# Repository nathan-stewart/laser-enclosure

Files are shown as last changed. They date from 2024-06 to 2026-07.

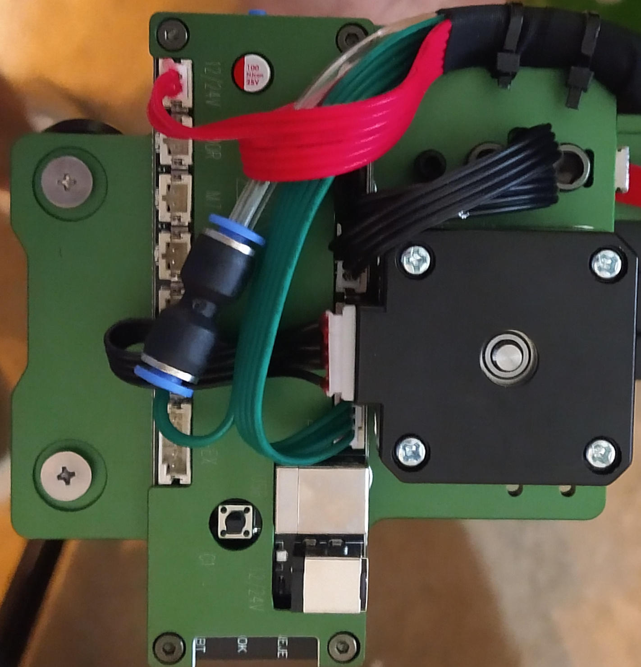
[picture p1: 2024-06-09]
neje-max-4/IMG_20240601_095933033.jpg

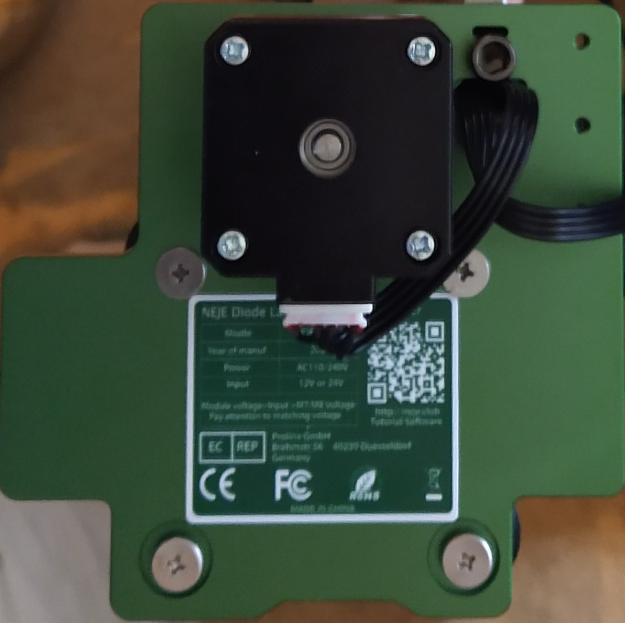
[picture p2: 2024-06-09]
neje-max-4/IMG_20240601_095917464.jpg

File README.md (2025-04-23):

# Laser Enclosure Fire Control Diagrams

This repository contains Graphviz DOT diagrams for documenting the fire suppression logic and relay control layout in a Raspberry Pi-controlled laser enclosure project.

## Included Files

### `fire_state_machine.dot`
- Describes the FIRE state logic.
- **ARMED**: Tank is pressurized (system ready).
- **FIRE**: Triggered by pressure drop, CO₂ valve opens, gates close.
- **RESET**: Performed via E-stop twist.
- Use `dot -Tpng fire_state_machine.dot -o fire_state_machine.png` to render.

### `power_distribution.dot`
- Updated relay layout with sequential relay numbering:
  - `K1`: Laser
  - `K2`: High Pressure Air (HPA)
  - `K3`: CO₂ Valve
  - `K4`: Blast Gates (intake/exhaust)
  - `K5`: Low Pressure Air (LPA)
  - `K6`: Heater Fan
  - `K7`: Exhaust Fan
  - `K8`: PTC Heater (AC)
- Use `dot -Tpng relay_layout_k3_k4_separated.dot -o relay_layout_k3_k4_separated.png` to render.

## Notes

- Gates are gravity-closing and do not remain activated after a FIRE event.
- CO₂ valve remains open until a manual reset is performed.
- The system arms based on tank pressure and triggers on pressure drop.
- Relays are powered from 24V, 12V, and AC lines as appropriate.

## Rendering

Install [Graphviz](https://graphviz.org/download/) and run:

```bash
dot -Tpng fire_state_machine.dot -o fire_state_machine.png
dot -Tpng power_distribution.dot -o power_distribution.png
```

Or use online editors like [edotor.net](https://edotor.net/) or [dreampuf.github.io](https://dreampuf.github.io/GraphvizOnline/).

---

**Enginerd-built. Fire-tested.** 🔥🛠️

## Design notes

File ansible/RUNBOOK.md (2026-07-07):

# Laser Enclosure Ansible Runbook

This folder intentionally has only three normal commands.

```bash
cd ansible
make ping
make app
make site
```

## Normal app/code update

Use this after changing HAL/control code, systemd unit files, GPIO boot block, or the halctl plugin source copied with the app.

```bash
make app DRY=1
make app
```

## Full box update

Use this for a rebuild or when base OS/kiosk/MeerK40t setup may need to be reapplied.

```bash
make site DRY=1
make site
```

## One-off narrower runs

Do not add a Makefile target for every Ansible feature. Use `EXTRA` when needed:

```bash
make site EXTRA='--tags meerk40t'
make site EXTRA='--tags base'
make app EXTRA='--tags gpio-config'
make app EXTRA='-vv'
```

## Live HAL commands

```bash
halctl get
halctl exhaust on
halctl exhaust off
halctl exhaust 600
```

## Current hardware notes

- Laser has its own fused 24 V feed.
- 12 V rail is fused and currently parked/reserved for future front panel.
- Spare moved from K4 to K2; verify code and GPIO comments match actual wiring.
- RJ45 fanout removed.
- PSU moved underneath board for space and airflow.
- White PowerCONs are switched 120 VAC outputs for DRY and FAN.

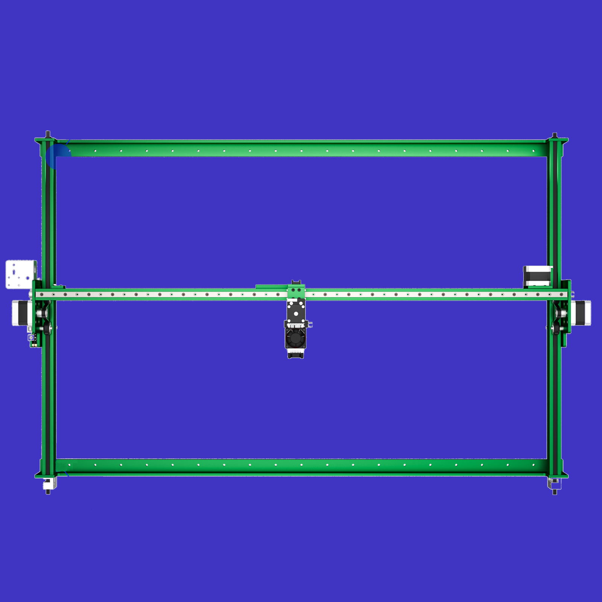
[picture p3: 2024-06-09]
neje-max-4/drawing-xy.jpg

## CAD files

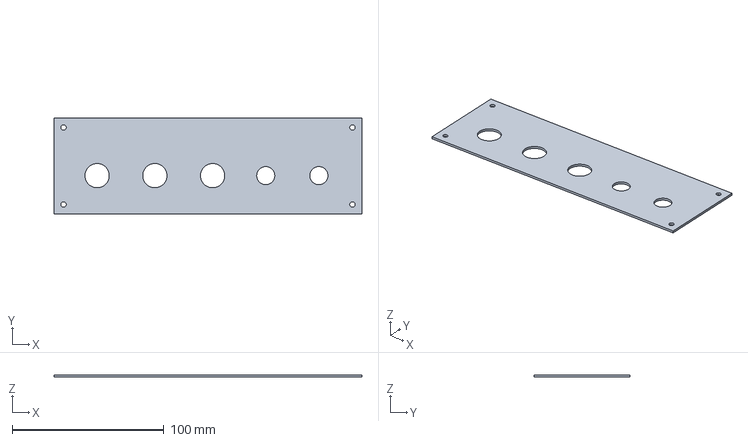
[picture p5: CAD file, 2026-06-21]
aluminum-bottom-panel.FCStd
203.2 x 63.5 x 1.52 mm

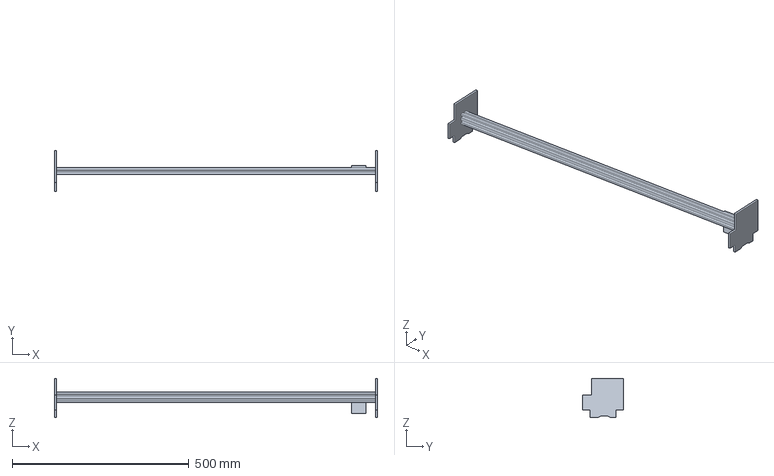
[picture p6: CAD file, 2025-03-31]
neje-max-4/x-rail.FCStd
914.2 x 116.0 x 111.0 mm

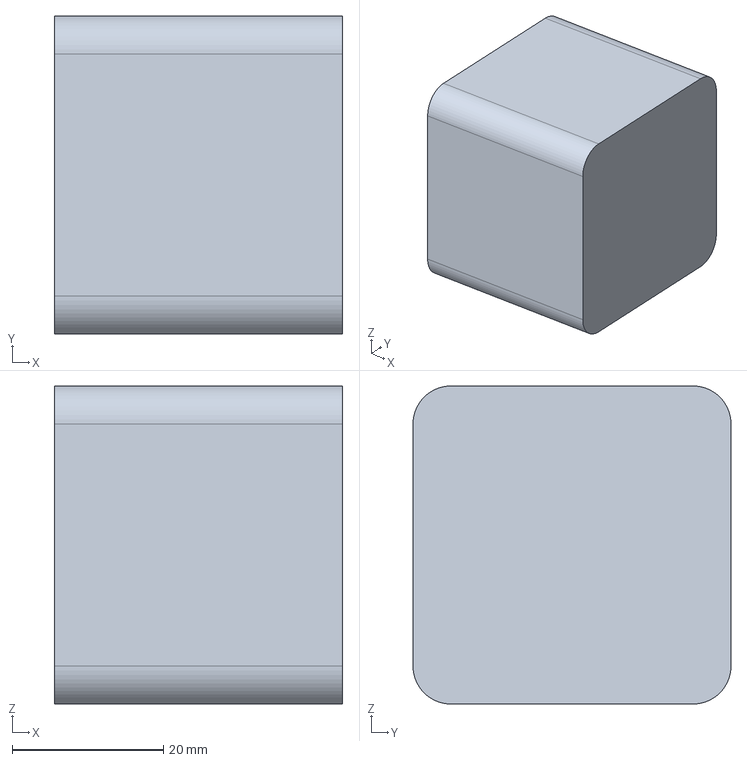
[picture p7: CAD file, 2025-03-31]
neje-max-4/nema-17.FCStd
38.1 x 42.0 x 42.0 mm

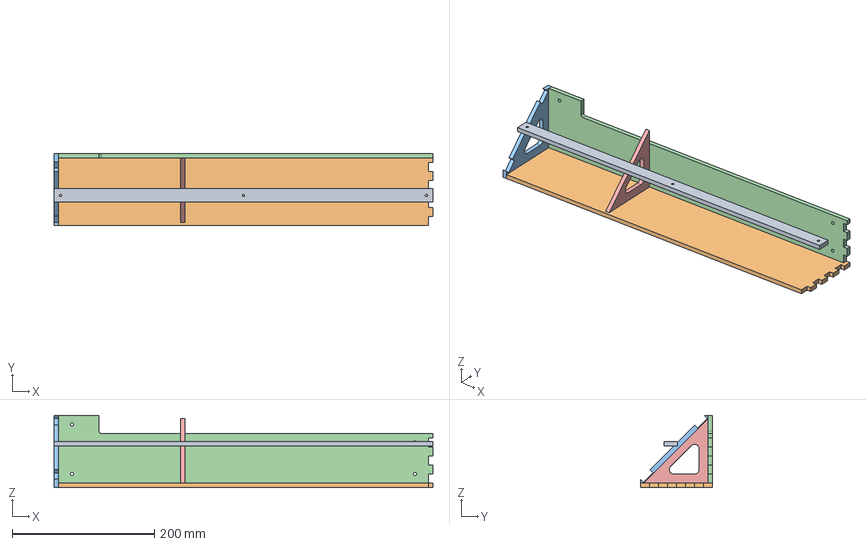
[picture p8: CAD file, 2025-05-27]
panel-support.FCStd
533.4 x 101.6 x 101.6 mm
floor
endcap
back
rib

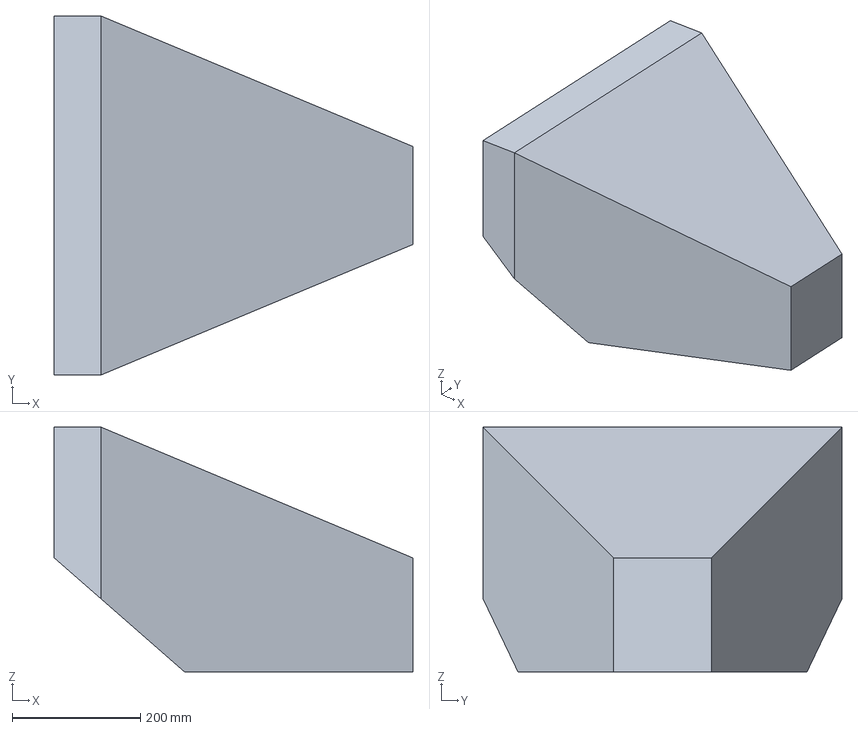
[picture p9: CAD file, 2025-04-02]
foamcore-duct.FCStd
558.8 x 558.8 x 381.0 mm

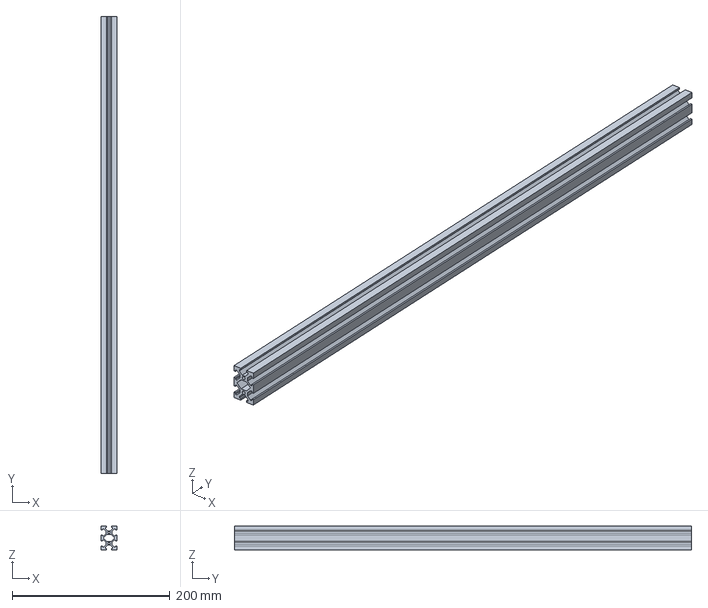
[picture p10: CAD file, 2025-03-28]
neje-max-4/y-extrusion.FCStd
20.0 x 580.0 x 30.0 mm

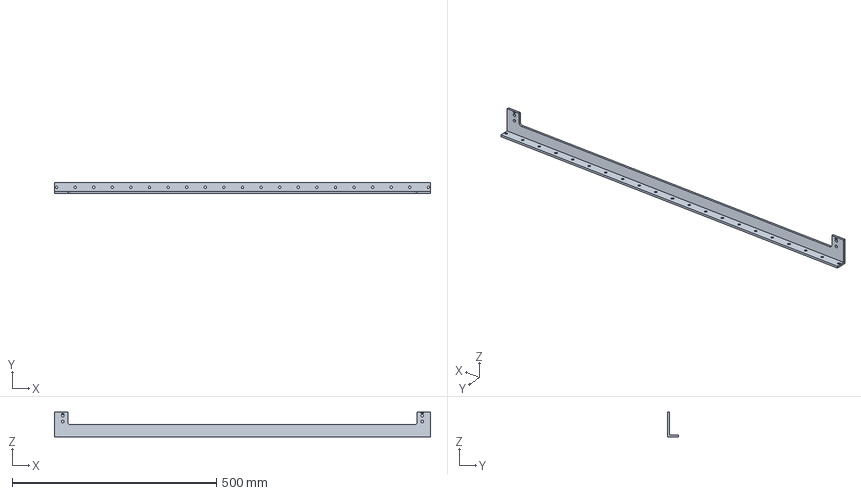
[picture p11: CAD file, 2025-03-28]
neje-max-4/x-frame.FCStd
920.0 x 26.0 x 60.0 mm

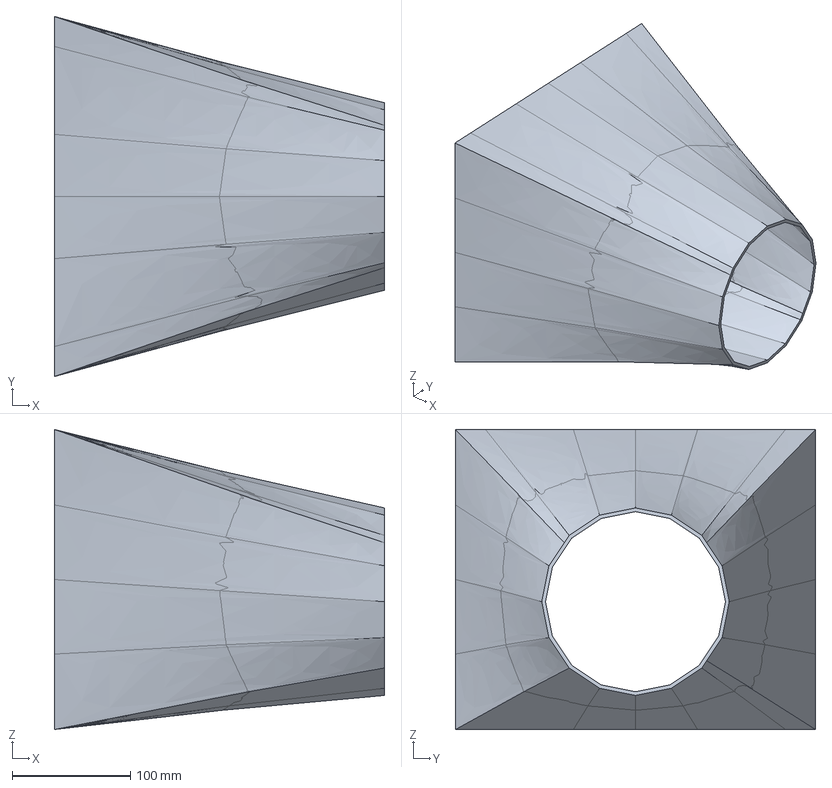
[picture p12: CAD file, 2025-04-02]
square-to-round.FCStd
279.4 x 304.8 x 254.0 mm

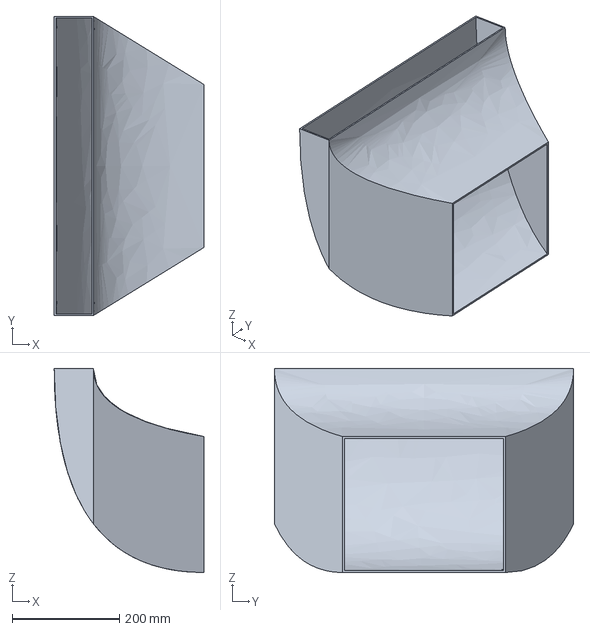
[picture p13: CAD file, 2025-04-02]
elbow.FCStd
279.4 x 558.8 x 381.0 mm

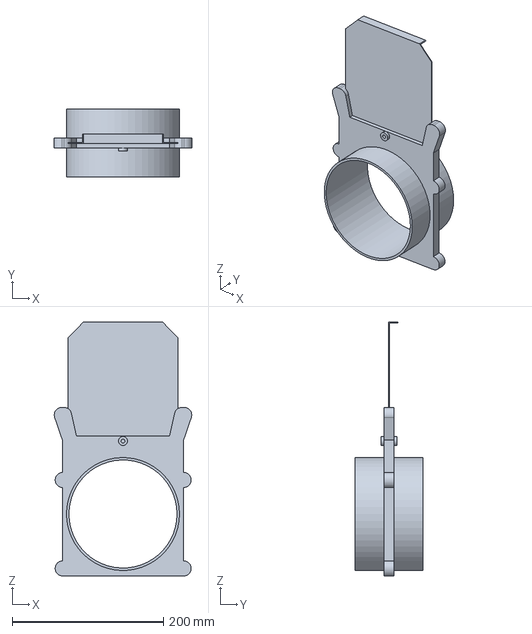
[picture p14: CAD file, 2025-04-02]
blastgate.FCStd
182.0 x 89.9 x 336.0 mm

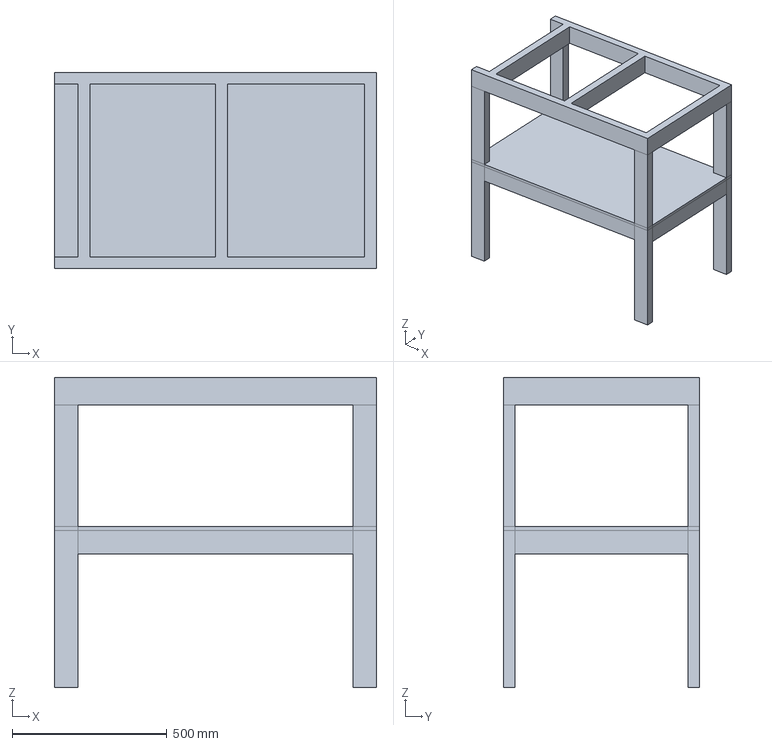
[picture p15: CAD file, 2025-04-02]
base.FCStd
1041.4 x 635.0 x 1003.3 mm

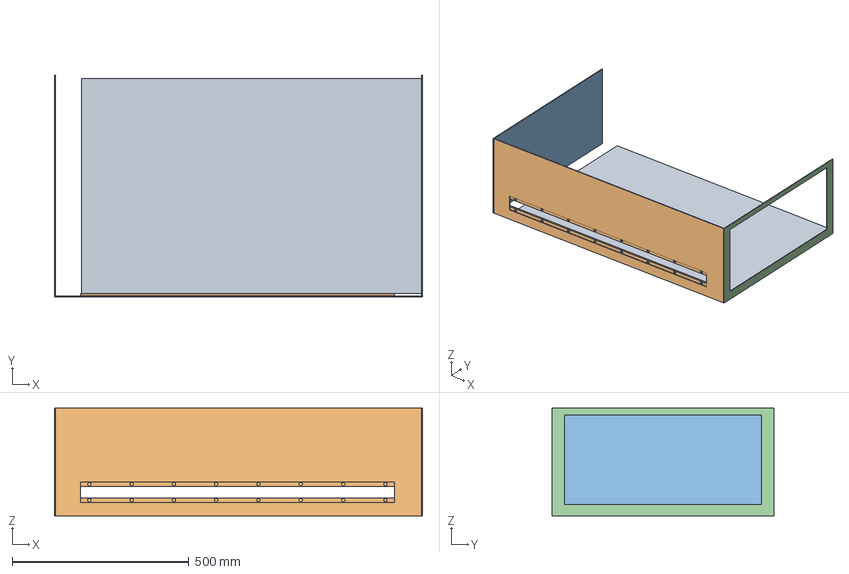
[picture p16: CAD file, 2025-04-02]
enclosure.FCStd
1041.4 x 628.6 x 304.8 mm
front
left
right

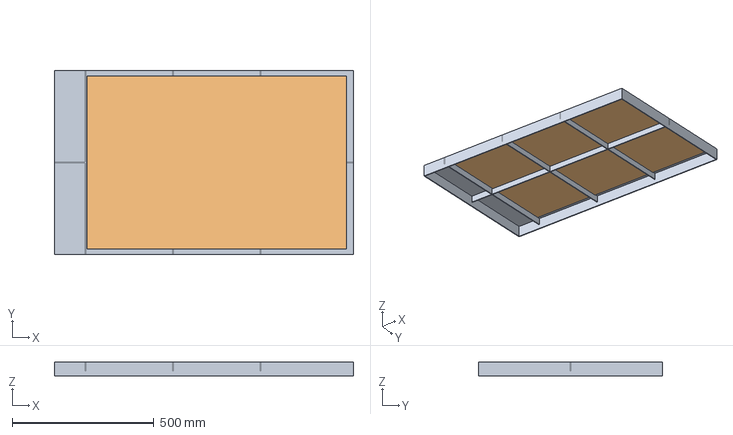
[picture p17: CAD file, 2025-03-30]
lid.FCStd
1054.1 x 647.7 x 50.8 mm
top
window

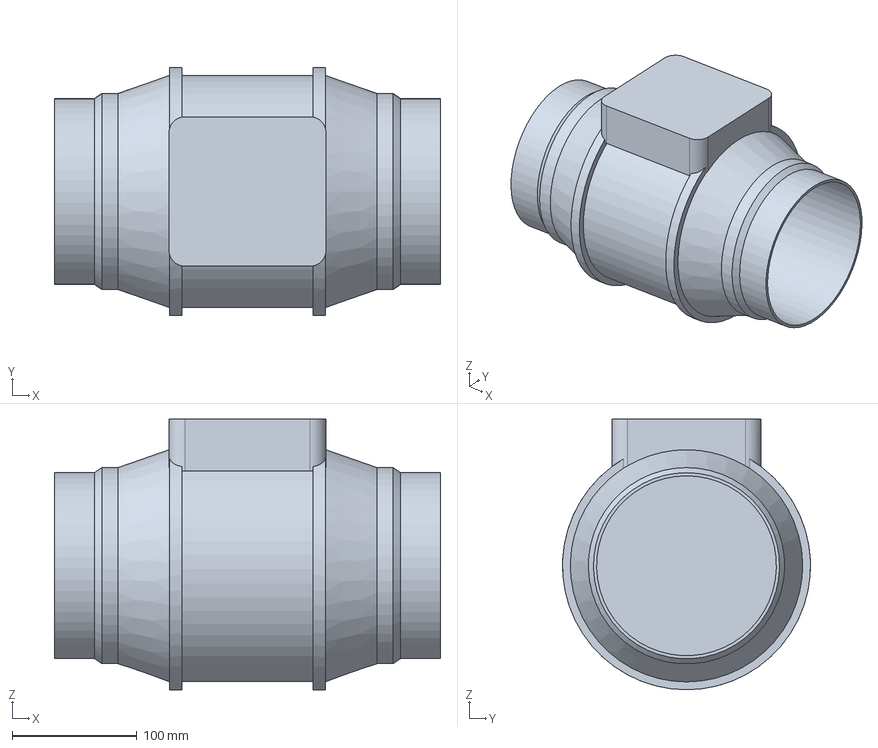
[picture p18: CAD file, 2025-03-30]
exhaust-fan.FCStd
309.9 x 199.0 x 217.2 mm

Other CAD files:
enclosure-assy.FCStd
neje-max-4/x-rail-assy.FCStd
neje-max-4/neje-max-4.FCStd
plug-mount.FCStd
90deg-register-box.FCStd
air-assist.FCStd
door.FCStd
dragchain-link.FCStd
dragchain-start.FCStd
duct-transition.FCStd
enclosure-dims.FCStd
enclosure-exploded.FCStd
exhaust-plenum.FCStd
intake.FCStd
onepiece.FCStd
rect-to-round.FCStd
reducer.FCStd
transition.FCStd

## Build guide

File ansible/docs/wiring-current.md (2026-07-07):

# Current wiring notes

Update this whenever the wiring reality changes.

- Laser power is on its own fused 24V feed, not the general 24V bus.
- 12V rail is fused, currently parked/reserved for future front panel use.
- PSU moved underneath the board for clearance and cooler air.
- RJ45 fanout removed.
- PowerCON white connectors are switched 120V outputs for DRY and FAN.
- Verify K2/K4 mapping in both code and `group_vars/all.yaml` before deployment.

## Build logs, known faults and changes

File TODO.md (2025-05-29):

# Laser Enclosure Tasks

## 🔧 System & Software
- [ ] Fix plymouth splash not showing
- [ ] Add watchdog for MCP23017
- [ ] App Design

## 🌡️ Sensors & Control
- [ ] Mount DHT11
- [ ] Design Sensor Board
- [ ] Build Sensor Board

## 🎛️ Panel & UI
- [ ] Build Control Panel Support Frame
- [ ] Build Control Panel 
- [ ] Wire relays
- [ ] Lights switched to K4

## 🛠️ Hardware Install
- [ ] Air Assist Install
- [ ] Extinguisher System Install

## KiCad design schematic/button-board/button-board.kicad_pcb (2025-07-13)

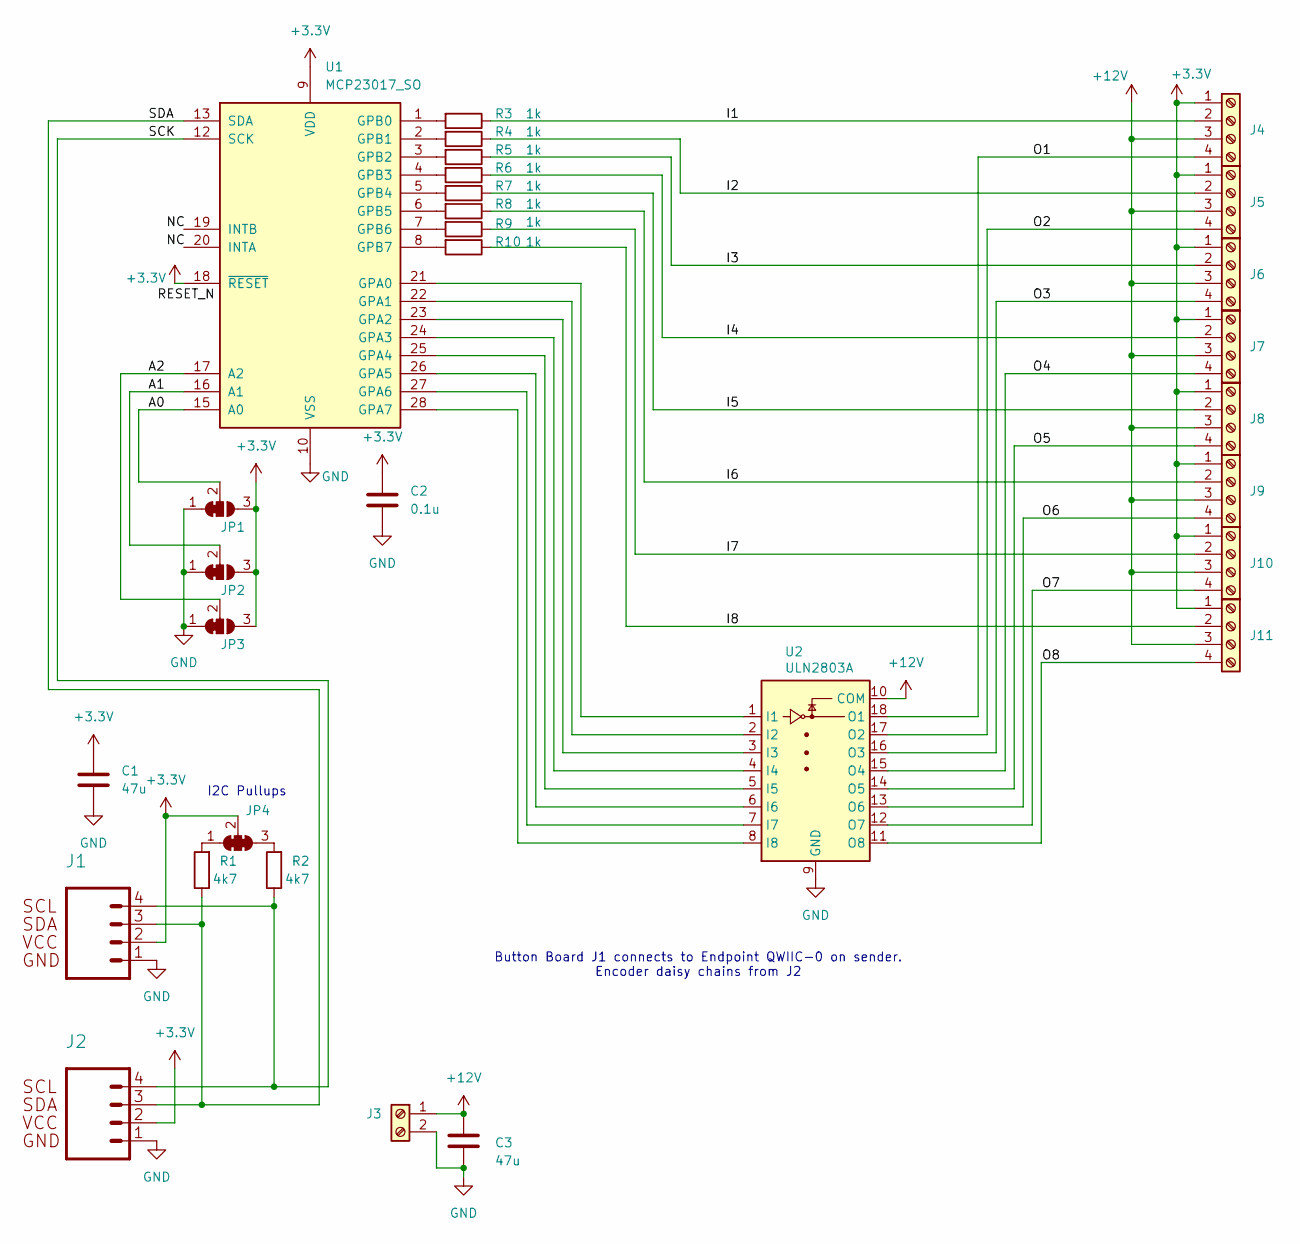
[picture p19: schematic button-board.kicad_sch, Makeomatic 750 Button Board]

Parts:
C1, C3: 47u; C_Radial_D6.3mm_H11.0mm_P2.50mm
C2: 0.1u; C_0805_2012Metric
J1, J2: 1x04_RA_SMD
J3: Screw_Terminal_01x02; TerminalBlock_Phoenix_MKDS-1,5-2-5.08_1x02_P5.08mm_Horizont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
J4, J5, J6, J7, J8, J9, J10, J11: Screw_Terminal_01x04; TerminalBlock_Phoenix_MKDS-1,5-4-5.08_1x04_P5.08mm_Horizont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
JP1, JP2, JP3: SolderJumper_3_Bridged12; SolderJumper-3_P1.3mm_Bridged12_RoundedPad1.0x1.5mm_NumberL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
JP4: SolderJumper_3_Bridged123; SolderJumper-3_P1.3mm_Bridged123_RoundedPad1.0x1.5mm_Number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
R1, R2: 4k7; R_0805_2012Metric
R3, R4, R5, R6, R7, R8, R9, R10: 1k; R_0805_2012Metric
U1: MCP23017_SO; SOIC-28W_7.5x17.9mm_P1.27mm
U2: ULN2803A; SOP-18_7.495x11.515mm_P1.27mm

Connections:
+3.3V: C1.1, C2.1, J1.2, J2.2, J4.1, J5.1, J6.1, J7.1, J8.1, J9.1, J10.1, J11.1, JP1.3 (B), JP2.3 (B), JP3.3 (B), JP4.2 (C), U1.9 (VDD), U1.18 (~RESET)
+12V: C3.1, J3.1, J4.3, J5.3, J6.3, J7.3, J8.3, J9.3, J10.3, J11.3, U2.10 (COM)
GND: C1.2, C2.2, C3.2, J1.1, J2.1, J3.2, JP1.1 (A), JP2.1 (A), JP3.1 (A), U1.10 (VSS), U2.9 (GND)
unnamed: J4.2, R3.1
unnamed: J4.4, U2.18 (O1)
unnamed: J5.2, R4.1
unnamed: J5.4, U2.17 (O2)
unnamed: J6.2, R5.1
unnamed: J6.4, U2.16 (O3)
unnamed: J7.2, R6.1
unnamed: J7.4, U2.15 (O4)
unnamed: J8.2, R7.1
unnamed: J8.4, U2.14 (O5)
unnamed: J9.2, R8.1
unnamed: J9.4, U2.13 (O6)
unnamed: J10.2, R9.1
unnamed: J10.4, U2.12 (O7)
unnamed: J11.2, R10.1
unnamed: J11.4, U2.11 (O8)
unnamed: JP1.2 (C), U1.15 (A0)
unnamed: JP2.2 (C), U1.16 (A1)
unnamed: JP3.2 (C), U1.17 (A2)
unnamed: JP4.1 (A), R1.2
unnamed: JP4.3 (B), R2.2
unnamed: U1.21 (GPA0), U2.1 (I1)
unnamed: U1.22 (GPA1), U2.2 (I2)
unnamed: U1.23 (GPA2), U2.3 (I3)
unnamed: U1.24 (GPA3), U2.4 (I4)
unnamed: U1.25 (GPA4), U2.5 (I5)
unnamed: U1.26 (GPA5), U2.6 (I6)
unnamed: U1.27 (GPA6), U2.7 (I7)
unnamed: U1.28 (GPA7), U2.8 (I8)
unnamed: R3.2, U1.1 (GPB0)
unnamed: R4.2, U1.2 (GPB1)
unnamed: R5.2, U1.3 (GPB2)
unnamed: R6.2, U1.4 (GPB3)
unnamed: R7.2, U1.5 (GPB4)
unnamed: R8.2, U1.6 (GPB5)
unnamed: R9.2, U1.7 (GPB6)
unnamed: R10.2, U1.8 (GPB7)
unnamed: J1.4, J2.4, R2.1, U1.12 (SCK)
unnamed: J1.3, J2.3, R1.1, U1.13 (SDA)

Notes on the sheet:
I2C Pullups
Button Board J1 connects to Endpoint QWIIC-0 on sender. Encoder daisy chains from J2

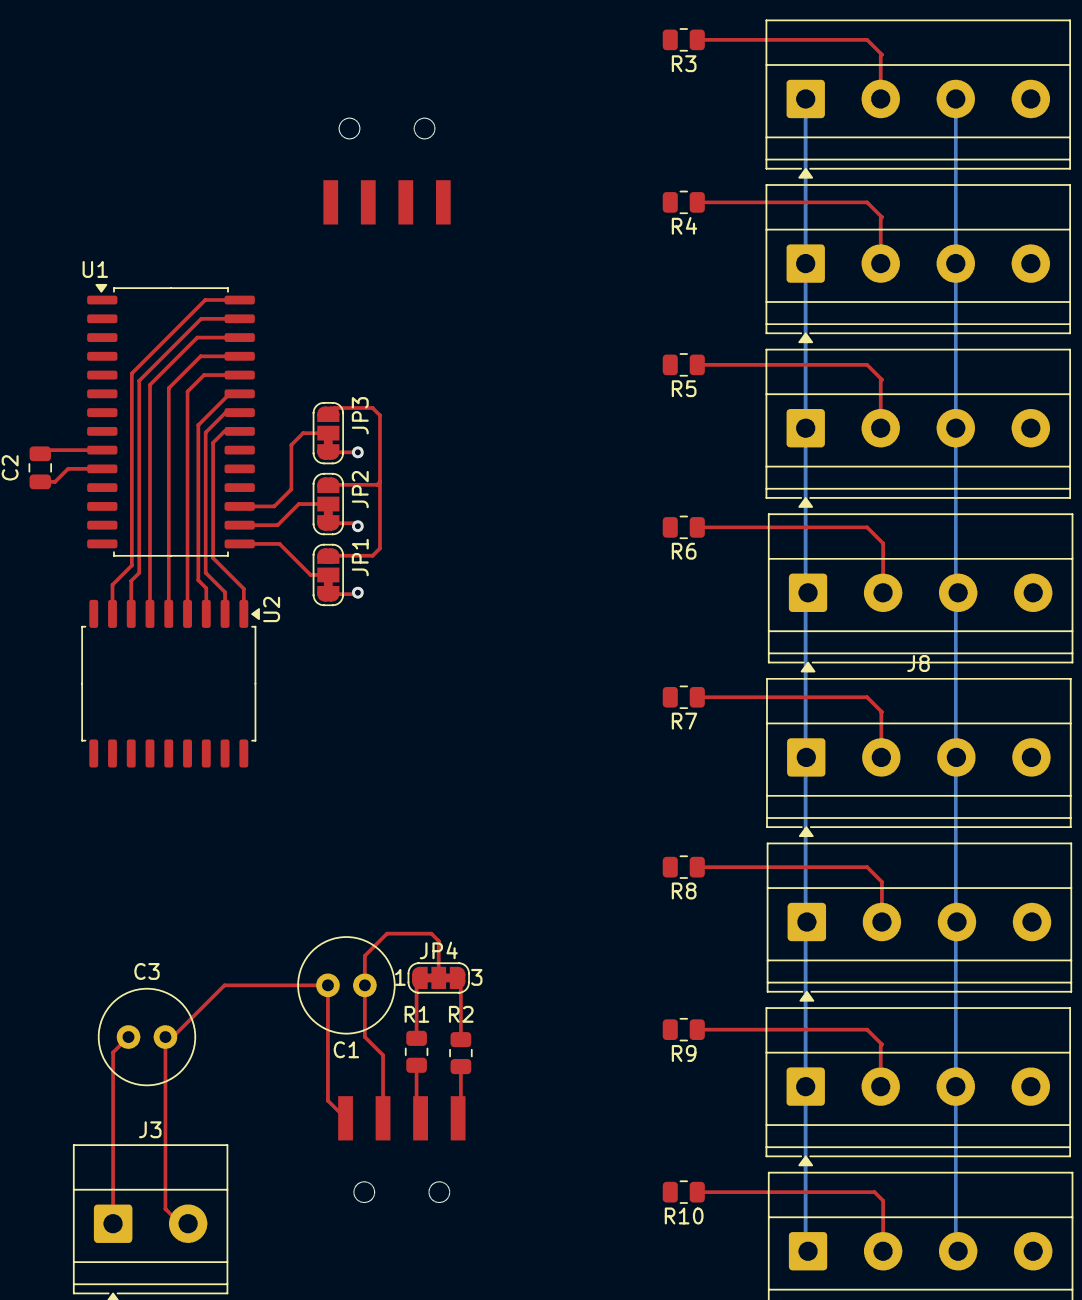
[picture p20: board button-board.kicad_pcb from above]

Board: 2 copper layers, 30 parts (0 on the bottom side), 42 nets.

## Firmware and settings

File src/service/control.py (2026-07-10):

#!/usr/bin/env python3
import sys
import os
import pwd
import argparse
import logging
import math
import inspect
import threading
import subprocess
import signal
import zmq
import json
import time
import threading
sys.path.insert(0, os.path.dirname(__file__))

ESTOP_BYPASS = True  # TEMPORARY: no physical E-stop wired

state_lock = threading.Lock()
stop_event = threading.Event()
state_hal = {}
hal_req_lock = threading.Lock()
log = None
pub = None
sub = None

def graceful_stop(signum, frame):
    log.info(f"Received signal {signum}, shutting down gracefully...")
    stop_event.set()

for sig in (signal.SIGTERM, signal.SIGINT, signal.SIGHUP):
    signal.signal(sig, graceful_stop)

last_commanded_outputs = {}
hal_exhaust_active = False

# Track activity for backlight control
ACTIVITY_INPUTS = {
    "i_fp0", "i_fp1", "i_fp2", "i_fp3",
    "i_estop", "i_m8",
    "i_axis_x", "i_axis_z", "i_coarse", "i_fine",
    "i_mask_encoder",
    "hal_exhaust_active", "hal_exhaust_mode",
}


RULE_INPUTS = set(ACTIVITY_INPUTS) | {"i_ambient_humidity"}
ENCODER_INPUTS = {"i_mask_encoder"}  # adjust if you rename or track deltas elsewhere
ENCODER_DELTA_THRESHOLD = 1  # define what counts as significant
previous_inputs = {}


# backlight control
IDLE_TIMEOUT = 5 * 60  # seconds
last_activity = time.monotonic()
last_display_state = None


def estop_active(i_estop=0):
    if ESTOP_BYPASS:
        return False
    return bool(i_estop)


def hal_ping():
    with hal_req_lock:
        try:
            req.send_json({"cmd": "get_status"})
            rep = req.recv_json()
            return isinstance(rep, dict) and rep.get("status") == "ok"
        except zmq.Again:
            return False


def wait_for_hal_ready(total_timeout=15.0, interval=0.25):
    end = time.monotonic() + total_timeout
    while time.monotonic() < end:
        if hal_ping():
            return True
        time.sleep(interval)
    return False


def getb(s, k):  # boolean read with default 0
    return bool(s.get(k, 0))


def num_ok(x):
    return isinstance(x, (int, float)) and math.isfinite(x)


def clamp01(x):
    return 0.0 if x < 0.0 else 100.0 if x > 100.0 else x


def dewpoint_rule(i_ambient_humidity=None, dryer_enable=0,
                  rh_on=50.0, rh_off=45.0,
                  min_on=30.0, min_off=30.0,
                  stale_timeout=180.0):
    now = time.monotonic()
    st = dewpoint_rule.__dict__
    last_change = st.get("last_change", 0.0)
    last_seen   = st.get("last_seen", 0.0)

    running = bool(dryer_enable)

    rh = None
    if isinstance(i_ambient_humidity, (int, float)) and math.isfinite(i_ambient_humidity):
        rh = max(0.0, min(100.0, float(i_ambient_humidity)))
        last_seen = now

    # stale -> fail safe OFF (respect min_on)
    if now - last_seen > stale_timeout:
        if running and (now - last_change) >= min_on:
            st["last_change"] = now; st["last_seen"] = last_seen
            return 0
        st["last_seen"] = last_seen
        return None

    cmd = None
    if rh is not None:
        if running and rh <= rh_off and (now - last_change) >= min_on:
            cmd = 0
        elif (not running) and rh >= rh_on and (now - last_change) >= min_off:
            cmd = 1

    if cmd is not None:
        log.debug(f'Humidity {rh:.1f} turning dryer {"on" if cmd else "off"} ')
        st["last_change"] = now; st["last_seen"] = last_seen
        return cmd

    st["last_seen"] = last_seen
    return None


# Rules for outputs - this is the brain stem - only handles low level rules
RULES = {
    # Neje Supports both M7 and M8 but Meerk40t only allows one or the other
    # tie both air assist functions to M8
    "laser_enable"      : lambda i_estop = 0                     : not estop_active(i_estop),
    "lpa_enable"        : lambda i_estop = 0, i_m8=0             : i_m8 and not i_estop and not estop_active(i_estop),
    "hpa_enable"        : lambda i_estop = 0, i_m8=0             : i_m8 and not i_estop and not estop_active(i_estop),
    "exhaust_enable"    : lambda i_estop=0, hal_exhaust_active=0 : hal_exhaust_active and not estop_active(i_estop),
    "dryer_enable"      : dewpoint_rule,
}


def start_heartbeat():
    while not stop_event.is_set():
        try:
            pub.send_string("heartbeat")
        except Exception:
            log.exception("heartbeat send failed")
        stop_event.wait(1.0)


def hal_set(name, value):
    payload = {"cmd": "set", "pin": name, "state": int(bool(value))}
    with hal_req_lock:
        try:
            log.debug("TX->HAL %s", payload)
            req.send_json(payload)
            reply = req.recv_json()
            log.debug("RX<-HAL %s", reply)
        except zmq.Again:
            log.error("HAL timeout waiting for reply to %s", payload)
            return False

        ok = isinstance(reply, dict) and str(reply.get("status", "")).lower() == "ok"
        if not ok:
            log.error("HAL NACK: %s", reply)
        return ok


def hal_get_status():
    req.send_json({"cmd":"get_status"})
    return req.recv_json()


def bind_kwargs_for(rule, state):
    if rule is None:
        return {}
    sig = inspect.signature(rule)
    kwargs = {}
    for name, p in sig.parameters.items():
        kwargs[name] = state.get(name, p.default if p.default is not inspect._empty else None)
    return kwargs


def rule_context(rule_state):
    keys = (
        "i_estop",
        "i_m8",
        "hal_exhaust_active",
        "dryer_enable",
        "i_ambient_humidity",
    )
    return " ".join(f"{k}={rule_state.get(k)!r}" for k in keys)


def apply_rules(state, now=None, version=None):
    global last_commanded_outputs

    rule_state = dict(state)

    decisions = {}
    for out, rule in RULES.items():
        if rule is None:
            continue
        try:
            res = rule(**bind_kwargs_for(rule, rule_state))
        except Exception as e:
            log.error("Rule %s failed: %s", out, e)
            continue
        if res is None:
            continue
        decisions[out] = int(bool(res))

    for k, v in decisions.items():
        cur = last_commanded_outputs.get(k)
        if v != cur:
            log.info(
                "Setting %s=%s; previous commanded=%s; %s",
                k, v, cur, rule_context(rule_state)
            )
            if hal_set(k, v):
                last_commanded_outputs[k] = v


def apply_rules_with_current_state():
    with state_lock:
        snapshot = dict(state_hal)
    apply_rules(snapshot)


def hal_listener():
    global last_activity, previous_inputs, state_hal_seq

    log.info("Starting hal listener...")

    # This should only be a reconciliation fallback. Normal response should
    # come from HAL PUB messages causing any_changed=True.
    tick_every = 10.0
    next_tick = time.monotonic() + tick_every

    while not stop_event.is_set():
        try:
            parts = sub.recv_multipart()

        except zmq.Again:
            # No HAL PUB message arrived before RCVTIMEO. Only run rules on
            # the periodic fallback.
            now = time.monotonic()
            if now >= next_tick:
                with state_lock:
                    snapshot = dict(state_hal)
                    state_hal_seq = state_hal_seq + 1 if "state_hal_seq" in globals() else 1
                    version = state_hal_seq

                apply_rules(snapshot, now=now, version=version)
                next_tick = now + tick_every

            continue

        except Exception:
            log.exception("hal_listener: recv failed")
            time.sleep(0.05)
            continue

        # Drain any queued HAL PUB frames so we evaluate rules once against the
        # newest available state, not once per stale intermediate frame.
        frames = [parts]
        while True:
            try:
                frames.append(sub.recv_multipart(flags=zmq.NOBLOCK))
            except zmq.Again:
                break
            except Exception:
                log.exception("hal_listener: drain recv failed")
                break

        now = time.monotonic()

        with state_lock:
            old_inputs = dict(previous_inputs)

            for p in frames:
                try:
                    msg = json.loads(p[-1])
                    st = msg.get("state", msg)
                except Exception:
                    log.exception("hal_listener: bad json")
                    continue

                if isinstance(st, dict):
                    state_hal.update(st)
                else:
                    log.warning("hal_listener: ignoring non-dict state payload: %r", st)

            new_inputs = {k: state_hal.get(k) for k in RULE_INPUTS}

            any_changed = False
            for key in RULE_INPUTS:
                prev = old_inputs.get(key)
                curr = new_inputs.get(key)

                if key in ENCODER_INPUTS:
                    try:
                        if abs(int(curr or 0) - int(prev or 0)) >= ENCODER_DELTA_THRESHOLD:
                            any_changed = True
                            break
                    except Exception:
                        # Ignore malformed encoder state for change detection.
                        pass

                elif curr is not None and curr != prev:
                    any_changed = True
                    break

            previous_inputs = new_inputs

            if any(
                key in ACTIVITY_INPUTS and new_inputs.get(key) is not None
                for key in ACTIVITY_INPUTS
            ):
                last_activity = now

            snapshot = dict(state_hal)
            state_hal_seq = state_hal_seq + 1 if "state_hal_seq" in globals() else 1
            version = state_hal_seq

        if any_changed or now >= next_tick:
            apply_rules(snapshot, now=now, version=version)

            if now >= next_tick:
                next_tick = now + tick_every

def is_laser_active():
    return state_hal.get("laser_enable", 0) == 1


def set_backlight(state: bool):
    env = os.environ.copy()
    env["DISPLAY"] = ":0"
    # Optional: add XAUTHORITY if needed, uncomment if problems occur
    # env["XAUTHORITY"] = "/home/kiosk/.Xauthority"

    cmd = ["vcgencmd", "display_power", "1" if state else "0"]
    try:
        subprocess.run(cmd, env=env, check=True)
    except subprocess.CalledProcessError as e:
        print(f"Failed to set display power: {e}")


def main(argv):
    global pub, sub, req, log, threads
    parser = argparse.ArgumentParser(description="HAL Watcher")
    parser.add_argument(
        "--log", "-l",
        default="INFO",
        choices=["DEBUG", "INFO", "WARNING", "ERROR", "CRITICAL"],
        help="Set the logging level (default: INFO)"
    )
    args = parser.parse_args()

    logging.basicConfig(
        level=getattr(logging, args.log),
        format="%(asctime)s [%(levelname)s] %(message)s",
        handlers=[logging.StreamHandler(sys.stdout)]
    )
    log = logging.getLogger("Rules")
    if ESTOP_BYPASS:
        log.warning("TEMPORARY ESTOP BYPASS ACTIVE: i_estop will not inhibit outputs")

    context = zmq.Context()
    sub = context.socket(zmq.SUB)
    sub.connect("tcp://localhost:5556")      # HAL PUB
    sub.setsockopt(zmq.SUBSCRIBE, b'')
    sub.setsockopt(zmq.RCVTIMEO, 500)

    req = context.socket(zmq.REQ)
    req.connect("tcp://localhost:5557")      # HAL REQ/REP
    req.setsockopt(zmq.RCVTIMEO, 500)
    req.setsockopt(zmq.SNDTIMEO, 500)

    pub = context.socket(zmq.PUB)
    pub.bind("tcp://*:5558")                 # Supervisor PUB
    pub.setsockopt(zmq.RCVTIMEO, 500)
    pub.setsockopt(zmq.SNDTIMEO, 500)

    if not wait_for_hal_ready():
        log.error("HAL not ready after timeout")
        sys.exit(1)

    threads = []
    threads.append(threading.Thread(target=hal_listener))
    threads.append(threading.Thread(target=start_heartbeat, daemon=True))

    log.info("Starting control threads...")
    for thread in threads:
        thread.start()

    try:
        while not stop_event.is_set():
            stop_event.wait(1.0)
    except KeyboardInterrupt:
        log.info("Shutting down...")
        stop_event.set()

    for thread in threads:
        thread.join()
    log.info("Exiting.")


if __name__ == "__main__":
    main(sys.argv)

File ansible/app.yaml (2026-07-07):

---
- name: Deploy laser enclosure HAL/control application
  hosts: laser
  become: true

  handlers:
    - name: Reload systemd
      systemd:
        daemon_reload: yes

    - name: Restart kiosk-hal
      systemd:
        name: kiosk-hal.service
        state: restarted

    - name: Restart kiosk-control
      systemd:
        name: kiosk-control.service
        state: restarted

  tasks:
    - name: Install HAL/control OS packages
      apt:
        name:
          - python3
          - python3-pip
          - python3-zmq
          - python3-pyqt5
          - python3-rpi-lgpio
          - python3-opencv
          - python3-sdnotify
          - fonts-dejavu
          - watchdog
        state: present
        update_cache: yes
      tags: [app, packages]

    - name: Install Adafruit/CircuitPython libraries system wide
      pip:
        name:
          - adafruit-circuitpython-ads1x15
          - adafruit-circuitpython-mcp230xx
          - adafruit-circuitpython-bme280
          - adafruit-circuitpython-seesaw
        executable: pip3
        extra_args: --break-system-packages
      tags: [app, python]

    - name: Ensure application directory exists
      file:
        path: "{{ app_dir }}"
        state: directory
        owner: "{{ kiosk_user }}"
        group: "{{ kiosk_user }}"
        mode: '0755'
      tags: [app]

    - name: Deploy application tree to kiosk
      copy:
        src: "{{ app_src }}"
        dest: "{{ app_dir }}/"
        owner: "{{ kiosk_user }}"
        group: "{{ kiosk_user }}"
        mode: preserve
      notify:
        - Restart kiosk-hal
        - Restart kiosk-control
      tags: [app, deploy]

    - name: Install halctl MeerK40t plugin from deployed local source
      pip:
        name: "{{ app_dir }}/meerk40t-halctl"
        executable: pip3
        extra_args: --break-system-packages --editable
      tags: [app, halctl, meerk40t]

    - name: Create HAL GPIO and sensor systemd service
      copy:
        dest: /etc/systemd/system/kiosk-hal.service
        mode: '0644'
        content: |
          [Unit]
          Description=HAL GPIO and Sensor Service
          After=network-online.target
          Wants=network-online.target
          StartLimitIntervalSec=30
          StartLimitBurst=5

          [Service]
          Type=simple
          Restart=on-failure
          RestartSec=5
          ExecStart=/usr/bin/python3 {{ app_dir }}/run_hal.py --log=DEBUG
          StandardOutput=journal
          StandardError=journal
          TimeoutStartSec=10
          KillSignal=SIGINT
          User={{ kiosk_user }}
          Group={{ kiosk_user }}
          WorkingDirectory={{ app_dir }}
          SyslogIdentifier=kiosk-hal

          [Install]
          WantedBy=multi-user.target
      notify:
        - Reload systemd
        - Restart kiosk-hal
      tags: [app, services, hal]

    - name: Create control layer systemd service
      copy:
        dest: /etc/systemd/system/kiosk-control.service
        mode: '0644'
        content: |
          [Unit]
          Description=Laser Control Logic Supervisor
          Requires=kiosk-hal.service
          After=kiosk-hal.service network-online.target
          Wants=network-online.target
          StartLimitIntervalSec=30
          StartLimitBurst=5

          [Service]
          Type=simple
          ExecStart=/usr/bin/python3 {{ app_dir }}/run_control.py --log=DEBUG
          Restart=on-failure
          RestartSec=5
          StandardOutput=journal
          StandardError=journal
          User={{ kiosk_user }}
          Group={{ kiosk_user }}
          WorkingDirectory={{ app_dir }}
          SyslogIdentifier=kiosk-control

          [Install]
          WantedBy=multi-user.target
      notify:
        - Reload systemd
        - Restart kiosk-control
      tags: [app, services, control]

    - name: Flush handlers before enabling services
      meta: flush_handlers
      tags: [app, services]

    - name: Enable and start kiosk services
      systemd:
        name: "{{ item }}"
        enabled: yes
        state: started
        daemon_reload: yes
      loop:
        - kiosk-hal.service
        - kiosk-control.service
      tags: [app, services]

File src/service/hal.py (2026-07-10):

#!/usr/bin/env python3
import sys
import logging
import argparse
import zmq
import time
import json
import threading
import signal

parser = argparse.ArgumentParser(description="HAL Watcher")
parser.add_argument(
    "--log", "-l",
    default="INFO",
    choices=["DEBUG", "INFO", "WARNING", "ERROR", "CRITICAL"],
    help="Set the logging level (default: INFO)"
)

parser.add_argument(
    "--mock", "-m",
    action="store_true",
    help="Run HAL with mock I2C devices for testing on non-Pi systems"
)
args = parser.parse_args()

import service.devices
service.devices.configure_mock(args.mock)
from service.devices import Gpio, Expander, AnalogRead, Environment, RotaryEncoder

from sdnotify import SystemdNotifier
notifier = SystemdNotifier()

wait_inputs = 1.0 / 40.0   # 40Hz for inputs
wait_sensors = 1.0 / 10.0  # 10Hz for sensors
wait_env = 5.0             # 30 seconds for environment
wait_config = 2  # seconds -  rescan periodically if lost comms
timeout_input = 0.5  # seconds
timeout_env = 180  # seconds
heartbeat_lock = threading.Lock()
stop_event = threading.Event()
state_lock = threading.Lock()
publish_lock = threading.Lock()
last_input_poll = last_sensor_poll = last_env_poll = time.time()
error_threshold = 5
DEBOUNCE_LEN = 3

def graceful_stop(signum, frame):
    log.info(f"Received signal {signum}, shutting down gracefully...")
    stop_event.set()

for sig in (signal.SIGTERM, signal.SIGINT, signal.SIGHUP):
    signal.signal(sig, graceful_stop)

pub = None
rep = None

current_state = {}
previous_snapshot = {}

rpi_gpio = Gpio()
#rpi_gpio.input(22, "i_m7")
rpi_gpio.input(27, "i_m8")
rpi_gpio.input(17, "i_estop")
for name in rpi_gpio.inputs.keys():
    current_state[name] = 0

rpi_gpio.output(7,  "k1_enable",  0)
rpi_gpio.output(8,  "laser_enable",  0)
rpi_gpio.output(25, "lpa_enable",  0)
rpi_gpio.output(24, "hpa_enable",  0)
rpi_gpio.output(23, "k5_enable",  0)
rpi_gpio.output(18, "k6_enable",  0)
rpi_gpio.output(12, "exhaust_enable",  0)
rpi_gpio.output(16, "dryer_enable",  0)
for name in rpi_gpio.outputs.keys():
    current_state[name] = 0

expanders = {}
expanders[0x20] = Expander(addr=0x20)
expanders[0x20].input(0,'i_fp0')
expanders[0x20].input(1,'i_fp1')
expanders[0x20].input(2,'i_fp2')
expanders[0x20].input(3,'i_fp3')
expanders[0x20].output(0, 'o_fp0')
expanders[0x20].output(1, 'o_fp1')
expanders[0x20].output(2, 'o_fp2')
expanders[0x20].output(3, 'o_fp3')

expanders[0x21] = Expander(addr=0x21)
expanders[0x21].input(0, 'i_mask_encoder')
expanders[0x21].input(1, 'i_axis_x')
expanders[0x21].input(2, 'i_axis_z')
expanders[0x21].input(3, 'i_coarse')
expanders[0x21].input(4, 'i_fine')
expanders[0x21].output(0, 'o_mask_encoder')

for expander in expanders.values():
    for name in expander.inputs.keys():
        current_state[name] = None
    for name in expander.outputs.keys():
        current_state[name] = None

encoder = RotaryEncoder()
current_state["encoder_delta"] = 0

adc = AnalogRead()
adc.input(0, "i_air_supply")
adc.input(1, "i_co2_supply")
for name in adc.inputs.keys():
    current_state[name] = None

ambient = Environment()
ambient.input('temperature', 'i_ambient_temp')
ambient.input('humidity',    'i_ambient_humidity')
ambient.input('pressure',    'i_ambient_pressure')
for name in ambient.inputs.keys():
    current_state[name] = None

current_state["hal_exhaust_active"] = 0
current_state["hal_exhaust_mode"] = "off"
current_state["hal_exhaust_duration"] = 0
current_state["hal_exhaust_until"] = 0.0

log = None
last_heartbeat = time.time()


def monitor_state_timers():
    while not stop_event.is_set():
        now = time.time()

        with state_lock:
            active = bool(current_state.get("hal_exhaust_active", 0))
            mode = current_state.get("hal_exhaust_mode")
            until = float(current_state.get("hal_exhaust_until") or 0.0)
            expired = active and mode == "timed" and until and now >= until

        if expired:
            log.info("Timed exhaust expired")
            set_hal_state({
                "hal_exhaust_active": 0,
                "hal_exhaust_mode": "off",
                "hal_exhaust_duration": 0,
                "hal_exhaust_until": 0.0,
            })

        stop_event.wait(0.25)


def publish_state(snapshot):
    with publish_lock:
        # change filter
        if snapshot == previous_snapshot:
            return

        pub.send_multipart([b"hal", json.dumps({"state": snapshot}).encode()])
        previous_snapshot.clear()
        previous_snapshot.update(snapshot)

def write_pin(pin, val):
    """Write one physical pin."""
    v = 1 if val else 0
    if pin in rpi_gpio.outputs:
        log.debug("Setting GPIO %s to %d", pin, v)
        rpi_gpio.write(pin, v)
        return True
    for exp in expanders.values():
        if pin in exp.outputs:
            exp.write(pin, v)
            return True
    log.error("Unknown output pin %s", pin)
    return False

def set_output(name, value):
    v = 1 if value else 0
    with state_lock:
        ok = True
        changed = False

        if current_state.get(name, 0) != v:
            if not write_pin(name, v):
                ok = False
            else:
                current_state[name] = v
                changed = True
        snap = dict(current_state)

    if changed:
        publish_state(snap)
    return ok

def set_hal_state(updates):
    """Update HAL-owned non-device state and publish it."""
    with state_lock:
        changed = False

        for k, v in updates.items():
            if not k.startswith("hal_"):
                log.error("Refusing to set non-HAL state key via set_hal_state: %s", k)
                return False

            if current_state.get(k) != v:
                current_state[k] = v
                changed = True

        snap = dict(current_state)

    if changed:
        publish_state(snap)

    return True


def control_heartbeat_listener():
    global last_heartbeat
    ctx = zmq.Context()
    sub = ctx.socket(zmq.SUB)
    sub.connect("tcp://localhost:5558")
    sub.setsockopt_string(zmq.SUBSCRIBE, "")
    sub.setsockopt(zmq.RCVTIMEO, 1000)  # 1s
    while not stop_event.is_set():
        try:
            msg = sub.recv_string()
            if msg == "heartbeat":
                last_heartbeat = time.time()
        except zmq.Again:
            continue
        except Exception:
            log.exception("heartbeat listener")
            break

def monitor_control_heartbeat():
    global last_heartbeat
    while not stop_event.is_set():
        if time.time() - last_heartbeat > 2:
            log.warning("WARNING: No heartbeat from control process. Taking emergency action.")
            # e.g., shut off laser GPIO
            panic_shutoff("control heartbeat lost")
        time.sleep(1)

def panic_shutoff(reason):
    log.warning("Fail-safe output shutdown: %s", reason)
    for name in list(rpi_gpio.outputs.keys()):
        set_output(name, 0)
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

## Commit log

2024-06-09 initial setup
    [base.FCStd, blastgate.FCStd, enclosure-assy.FCStd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]
2024-06-10 tweaks to back
    [base.FCStd, enclosure-assy.FCStd, enclosure.FCStd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]
2024-06-11 major changes to enclosure and rework of machine
    [door.FCStd, tabletop.FCStd, top-sides.FCStd]
2024-06-12 added new files
    [dimensions.FCStd, exhaust-fan.FCStd]
2024-06-12 updates to 1/4 in thick plywood
    [door.FCStd, enclosure-assy.FCStd, enclosure.FCStd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]
2024-06-12 renamed speadsheet (machine will have its own)
    [enclosure-dims.FCStd]
2024-06-12 spreadsheet updates
    [enclosure-assy.FCStd, enclosure-dims.FCStd, enclosure.FCStd]
2024-06-13 spreadsheet updates, working on ducting
    [90deg-register-box.FCStd, door.FCStd, duct-transition.FCStd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]
2024-06-14 changing duct system over to floor
    [base.FCStd, door.FCStd, enclosure-assy.FCStd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]
2024-06-15 added exhaust plenum, gate, elbow
    [air-assist.FCStd, base.FCStd, blastgate.FCStd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]
2024-06-15 tweaks to the basE
    [base.FCStd, blastgate.FCStd, door.FCStd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]
2024-06-15 intake tweaks
    [base.FCStd, door.FCStd, enclosure-assy.FCStd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]
2024-06-16 lid cleanup
    [base.FCStd, enclosure-assy.FCStd, enclosure-dims.FCStd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]
2024-07-03 tweaks to base, air assist
    [air-assist.FCStd, base.FCStd, blastgate.FCStd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]
2025-03-06 rework in progress
    [air-assist.FCStd, base.FCStd, blastgate.FCStd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]
2025-03-17 new files
    [elbow.FCStd, enclosure.FCStd, onepiece.FCStd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]
2025-03-24 air duct changes
    [air-assist.FCStd, base.FCStd, blastgate.FCStd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]
2025-03-26 updates to base
    [base.FCStd, elbow.FCStd, enclosure-assy.FCStd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]
2025-03-28 updates to lid
    [enclosure-assy.FCStd, enclosure.FCStd, lid.FCStd]
2025-03-30 update leg size to existing stock
    [base.FCStd, elbow.FCStd, enclosure-assy.FCStd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]
2025-03-30 reworking the enclosure
    [enclosure-assy.FCStd, enclosure.FCStd]
2025-03-31 reworking enclosure
    [elbow.FCStd, enclosure-assy.FCStd, enclosure.FCStd]
2025-03-31 housing updates
    [base.FCStd, elbow.FCStd, enclosure-assy.FCStd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]
2025-03-31 resizing base
    [elbow.FCStd, enclosure-assy.FCStd, enclosure.FCStd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]
2025-04-02 updates to as-built frame
    [base.FCStd, blastgate.FCStd, elbow.FCStd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]
2025-04-02 added foamcore duct
    [enclosure-assy.FCStd, foamcore-duct.FCStd, square-to-round.FCStd]
2025-04-03 fixed some ehaust assemblies
    [enclosure-assy.FCStd]
2025-04-23 switched to 21" panels
2025-04-23 moved emergency to switch panel to free up real estate
2025-04-24 added spacer and bezel
2025-04-24 create loopback video device
2025-04-25 fixed estop hole
2025-04-25 added zero set button, icons for actions
2025-04-26 split boards
2025-04-27 checked in encoder-mount file
2025-04-28 fixed pem, 12v, relays, encoder, fuse block, 5v
2025-04-29 tweaks to hole tests, created panel suppport profile
2025-05-03 final version of din mount cutouts
2025-05-03 added tplink board
2025-05-05 added ADC, fixed usb
2025-05-05 added adc board
2025-05-06 moved panel support box to freecad
    [panel-support.FCStd]
2025-05-07 go to electronic fire extinguisher button
2025-05-08 reworking panel for finger support
    [panel-support.FCStd]
2025-05-08 tweaks to panels
    [panel-support.FCStd]
2025-05-09 panel updates
    [panel-support.FCStd]
2025-05-10 mirrored to get the ends right
    [panel-support.FCStd]
2025-05-19 part to build - working on cam now
    [panel-support.FCStd]
2025-05-19 ready to cut
    [panel-support.FCStd]
2025-05-27 updates to panel
    [panel-support.FCStd]
2025-05-28 panel tweak - moving to soft buttons
2025-05-29 reworked ansible, added todo
    [front_panel.py]
2025-05-30 added control board mount cuts to git
2025-06-15 switch dht11 libs
2025-06-17 graceful thread exit
2025-06-21 pin changes for dht11
2025-06-21 thread handling, logging
2025-06-21 clean missing device handling and rescan
    [hal.py]
2025-06-21 thread cleanup
2025-06-22 added debounce, fixed expander bug
    [hal.py, pinmap.py]
2025-06-22 send updates at 40hz
2025-06-28 added relay test script
2025-07-01 fixed v4l, removed loopback
    [run_gui.py]
2025-07-01 zmq, fixed hal service, buttons
    [hal.py, run_gui.py]
2025-07-02 add heartbeat to shut down laser if control died
2025-07-03 fixed warnings, errors in services
    [control.py, hal.py]
2025-07-03 added encoder board
    [encoder-board.kicad_pcb, encoder-board.kicad_sch]
2025-07-03 encoder board first pass
    [encoder-board.kicad_sch]
2025-07-10 schematic updates
    [encoder-board.kicad_pcb, encoder-board.kicad_sch]
2025-07-10 renamed board
    [button-board.kicad_pcb, button-board.kicad_sch]
2025-07-11 finalized button board, added sensor board
    [button-board.kicad_sch, sensor-board.kicad_pcb, sensor-board.kicad_sch]
2025-07-11 added sensor board
2025-07-11 replaced individual transistors with array
    [button-board.kicad_sch]
2025-07-13 layout work
    [button-board.kicad_pcb, button-board.kicad_sch]
2025-07-13 updated net labels for pcb layout, added sender board
    [button-board.kicad_pcb, button-board.kicad_sch, sender-board.kicad_pcb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]
2025-07-13 added pico i2c test
2025-07-14 add the encoder to the 40hz polling
2025-07-14 likely broken but rewrite of missing device handling
    [hal.py]
2025-07-14 i2c cleanup
2025-07-15 start the watchdogs to shut down the laser if control isn't running
2025-07-18 started rework for mock devices
    [hal.py, mock_devices.py, pinmap.py]
2025-07-18 fixed syntax on expanders
    [hal.py]
2025-07-18 added encoder wrapper
2025-07-20 rework of mock device system
    [hal.py, mock_devices.py, real_devices.py]
2025-07-20 removed pin class
2025-07-20 named threads
2025-07-22 fixed i2c addr in real devices
    [real_devices.py]
2025-07-22 added EMA filtering to analog
2025-07-23 switched to yields
2025-07-24 fixed monitor thread launch
    [hal.py, real_devices.py]
2025-07-24 fixed set_outputs to new mechanism
    [hal.py]
2025-07-24 fixed double queue, turn generators into dicts for remaining devices
    [hal.py, real_devices.py]
2025-07-24 fixed missing outputs if no inputs received
    [hal.py]
2025-07-24 fixed set_output message reply objects
    [hal.py]
2025-07-24 populate state struct so missing in/outs don't mess up control - it's sorta simple
    [control.py, hal.py]
2025-07-25 brightness not suppored - use hdmi power
2025-07-26 fixed din leg holes
2025-07-28 added sender board
2025-07-28 inverted logic for rpi gpios
    [hal.py, real_devices.py]
2025-08-06 fixed typo in camera stream
2025-08-10 library import partial fixes
    [real_devices.py]
2025-08-10 fixed additional circuitpython imports
    [real_devices.py]
2025-08-10 made mock consistent with real, fixed debounce bugs
    [mock_devices.py, real_devices.py]
2025-08-10 add channel limit to adc
2025-08-11 adc now working
2025-08-13 log devices on config
2025-08-15 fied lock issue with control message
    [control.py]
2025-08-16 added virtual outputs to tie fan/heater togther
2025-08-18 reworked virtual gpio system - WIP
    [control.py, hal.py]
2025-08-18 fix encoder bug
2025-08-18 fixed bug in encoder, watchdog
    [hal.py, real_devices.py]
2025-08-18 renamed gpio instance to rpi_gpios to avoid shadowing
    [hal.py]
2025-08-18 fixed but in set_output
    [hal.py]
2025-08-19 fix state for virtuals
    [control.py, hal.py]
2025-08-19 debugging slaved pin polarity
2025-08-19 make gpio read tolerant of pin inputs
2025-08-20 fixed debug out for gpio writes
    [hal.py, real_devices.py]
2025-08-20 removed virtual_outputs and combined heater/fan with a single ac device
2025-08-20 removed virtual gpios, fixed bug in dryer
    [control.py, hal.py]
2025-08-23 added panel mount for solenoid plugs
    [plug-mount.FCStd]
2025-08-23 inlet acrylic, add labels, reduce wood holes to screw size
2025-08-24 updated cut file
2025-08-24 started combining boards
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2025-09-24 made a vcarve/drill version in aluminum
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2026-05-15 fixed bug in halctl/virtuals
    [control.py]
2026-05-16 fixed bug in purge timing
    [control.py]
2026-06-11 Added LPA back for aquarium pump/side jet
2026-06-21 major rework - relays, panel, new command structure, meerk40t module
    [control.py, hal.py]
2026-07-07 reworked ansible, moved hpa/lpa/spare
    [app.yaml, control.py, hal.py]
2026-07-10 allowed estop bypass w warning, fixed output mapping/removed abstraction layer - all abstraction is done in hal now, not distributed to control
    [control.py, hal.py]
